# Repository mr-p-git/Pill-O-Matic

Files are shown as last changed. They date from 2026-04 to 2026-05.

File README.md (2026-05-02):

# Pill-O-Matic: Real-Time Scheduled Automatic Pill Dispenser

- Arduino-based automatic pill dispenser with sensor-driven safety logic and stepper-controlled mechanical dispensing.

## Documentation

- [System Design and Implementation](Pill-O-Matic_System_Design_and_Implementation.md) 
- [Project Summary](Pill-O-Matic_Project_Summary.md) 

## Demonstration
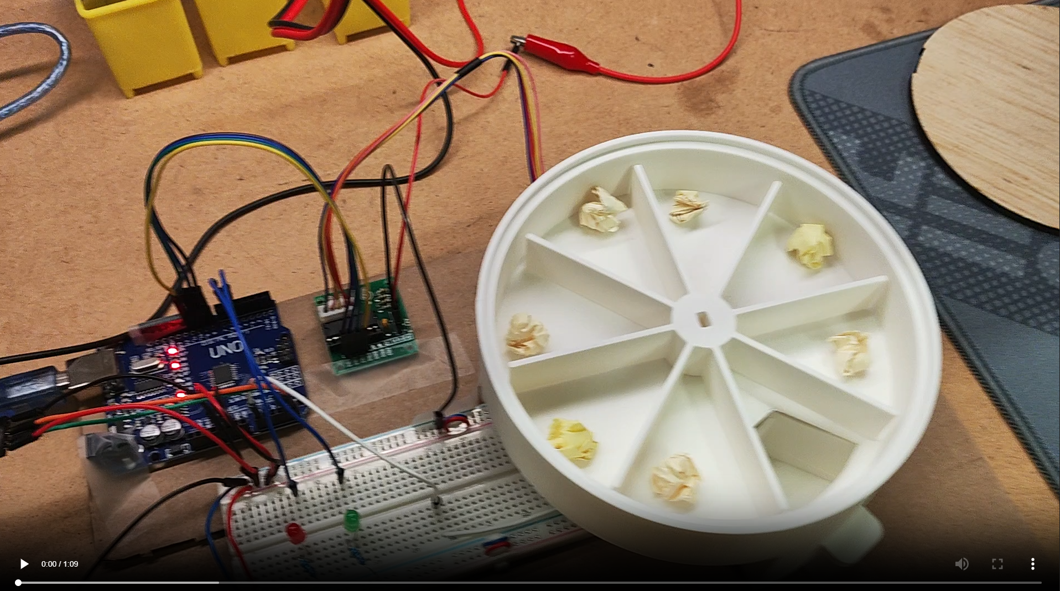
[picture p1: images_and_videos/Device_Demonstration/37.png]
Pill-O-Matic Demo (https://github.com/user-attachments/assets/4b54a555-bc47-4cf3-90d2-f38e5f574e28)


## Project Overview

Pill-O-Matic is a real-time scheduled automatic pill dispenser designed to deliver single doses of medication at predefined times throughout the day. The system integrates sensing, timing, control logic, and mechanical actuation to ensure reliable and user-aware dispensing.

An Arduino Uno coordinates the system using a DS3231 real-time clock (RTC) module for accurate scheduling. At each scheduled time, the system verifies tray presence using an analog Hall effect sensor before actuating a stepper motor to rotate a compartmentalized pill wheel and dispense one dose. The system prevents incorrect operation through state-based logic, ensuring pills are only dispensed when appropriate conditions are met.

## Technical Highlights

- **Embedded firmware development:** Programmed Arduino control logic for RTC-based scheduling, Hall sensor tray detection, LED status feedback, and stepper motor actuation.
- **Electromechanical system integration:** Integrated sensing, timing, motor control, and mechanical dispensing into a coordinated automated medication system.
- **Sensor-based safety control:** Used tray-presence detection to prevent dispensing when the tray is missing and reduce the risk of duplicate or unsafe dispensing.
- **Real-time scheduled operation:** Implemented DS3231 RTC-based dose timing so dispensing events occur autonomously at predefined medication times.
- **Indexed stepper motor control:** Drove a 28BYJ-48 stepper motor through a ULN2003 driver to rotate the pill wheel by fixed increments for single-dose dispensing.
- **State-based control logic:** Structured system behavior around idle, tray-missing, dispensing, and pill-waiting states for predictable user interaction.
- **Power-conscious actuator design:** De-energized the stepper motor when idle to reduce heat, current draw, and unnecessary standby power use.
- **Rapid hardware prototyping:** Fabricated and tested a mixed-material prototype combining 3D-printed PLA mechanisms, embedded magnets, a plywood lid, and cardboard-mounted electronics.

## Key Features

- Real-time scheduled dispensing using RTC-based timing  
- Sensor-based tray detection using analog Hall effect sensor (SS49E)  
- Stepper motor-driven mechanical indexing (45° per dose)  
- State-based control logic to prevent missed or duplicate dispensing  
- User interaction detection via tray removal (no buttons required)  
- Energy-efficient motor control with zero idle current draw  

## System Architecture

- **Controller:** Arduino Uno  
- **Timing Module:** DS3231 Real-Time Clock (RTC)  
- **Sensor:** SS49E Analog Hall Effect Sensor  
- **Actuator:** 28BYJ-48 5V Stepper Motor + ULN2003 Driver  
- **User Feedback:** Red and Green LEDs  
- **Power:** External 5V supply for motor (shared ground with Arduino)  

## System Operation

1. The RTC continuously tracks real time  
2. The Arduino checks scheduled dispensing times  
3. The Hall sensor verifies tray presence  
4. If conditions are met, the stepper motor rotates 45° to dispense one dose  
5. The system waits for tray removal before allowing the next dispense  
6. If the tray is missing or a pill is still present, dispensing is blocked  

## Fabrication and Materials

- 3D-printed PLA pill wheel and tray for precise geometry  
- Plywood lid for enclosure support and accessibility  
- Solderless breadboard for circuit prototyping  
- Embedded magnets for tray detection  

## Key Design Decisions

- Selected Hall effect sensing over force-based detection due to low pill weight, improving reliability  
- Implemented state-based logic to handle missed doses and prevent unsafe operation  
- Disabled stepper motor holding current to reduce power consumption and prevent overheating  
- Designed mechanical clearances to ensure smooth motion without post-processing  
- Used a hybrid material approach (PLA + plywood) to balance precision and structural simplicity  

## Future Improvements

- Improve enclosure robustness and overall durability  
- Integrate user interface (LCD display or alert system)  
- Add battery power for standalone operation  
- Enable wireless connectivity for remote monitoring and notifications  
- Expand system with data logging and health tracking features  

## Outcome

This project demonstrates the successful design and integration of an electromechanical system combining hardware, firmware, and mechanical components. The final prototype reliably performs time-based dispensing with sensor-driven safety logic and efficient power management, showcasing practical engineering problem-solving and system-level thinking.

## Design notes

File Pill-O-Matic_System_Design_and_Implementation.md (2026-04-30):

# Pill-O-Matic: Real-Time Scheduled Automatic Pill Dispenser

## Project Description

This project presents the design and implementation of a real-time clock-based automatic pill dispenser that delivers medication at predefined times throughout the day. The system integrates sensing, timing, control logic, and actuation to ensure reliable and user-aware dispensing. The core of the system is an Arduino Uno, which coordinates all subsystems. A DS3231 real-time clock module provides accurate timekeeping and enables scheduling of multiple daily dose times. At each scheduled time, the system checks the state of the pill tray using an analog Hall effect sensor (SS49E), which detects whether the tray is inserted via mini magnets. If the tray is in place, a 28BYJ-48 5V stepper motor, driven by a ULN2003 driver, rotates a compartmentalized pill wheel by 45 degrees to dispense one dose. A green LED indicates that a pill has been dispensed and is waiting in the tray, while a red LED indicates that the tray is missing and dispensing is temporarily blocked. The system implements state-based control logic to ensure safe and correct operation, including detecting tray removal as a user action to take the medication and preventing dispensing when:

- the tray was not removed following the dispense of a previous dose, indicating that the user forgot to take the pills, and the pills are still in the tray.
- the tray is absent, indicating that the user forgot to return the tray.

The mechanical structure of the dispenser consists of a 3D-printed pill wheel and tray, fabricated using PLA to enable precise geometry and rapid prototyping of the rotating compartment system, while providing rigidity and stability for mounting the motor and holding multiple doses of medication. A plywood lid is used to enclose and support the top of the device, allowing easy access for maintenance and refilling. This combination of materials allows for a balance between cost, manufacturability, structural support, and ease of modification during the design process. Additionally, the motor is fully de-energized after each movement to minimize power consumption and prevent overheating. The circuit is implemented on a solderless breadboard as a functional prototype, demonstrating a complete and integrated electromechanical system without permanent embedded hardware fabrication.The system was validated through repeated testing across multiple scheduled events, demonstrating reliable time-based triggering, consistent mechanical dispensing, and stable sensor-driven state transitions. Future work may focus on improving enclosure robustness, integrating a user interface such as an LCD display or alert system, and enabling wireless connectivity for remote monitoring and configuration, moving the design toward a deployable assistive device.

## Key Features

- Time-based automated pill dispensing using RTC scheduling
- Sensor-driven safety logic to prevent incorrect dispensing
- Mechanical indexing system with precise 45° rotation per dose
- Energy-efficient motor control with zero idle current draw
- User-aware interaction via tray detection instead of manual input

## Design Constraints

1. Budget control: $200 max
2. Include electrical, mechanical, and software/firmware system

## Engineering Challenges and Design Decisions

- Selected Hall effect sensing over force-based detection after determining that pill mass was insufficient for reliable actuation, improving system robustness.
- Implemented state-based control logic to handle edge cases such as missed doses and tray removal, ensuring safe and predictable operation.
- Optimized stepper motor control by eliminating idle coil energization, reducing power consumption and preventing thermal buildup.
- Designed precise mechanical interfaces using calibrated clearances (0.2–0.6 mm) to ensure proper fits and reliable motion without post-processing.
- Balanced material selection by combining 3D-printed PLA for complex geometry and plywood for structural simplicity and accessibility.

## System Architecture

### Microcontroller

- Arduino UNO R3: program the RTC so that at a preset time, pill would be dispensed. Program the Stepper motor to rotate 1/8 of a full rotation everytime it receives a signal from the RTC.

### Input Devices

- DS3231 RTC module: a real-time-clock module. Pre-set time to take pill (e.g 8:00 a.m. EST). Sends signal to stepper motor to rotate 1/8 of a full rotation, turns on Green LED when it's time to take pill.

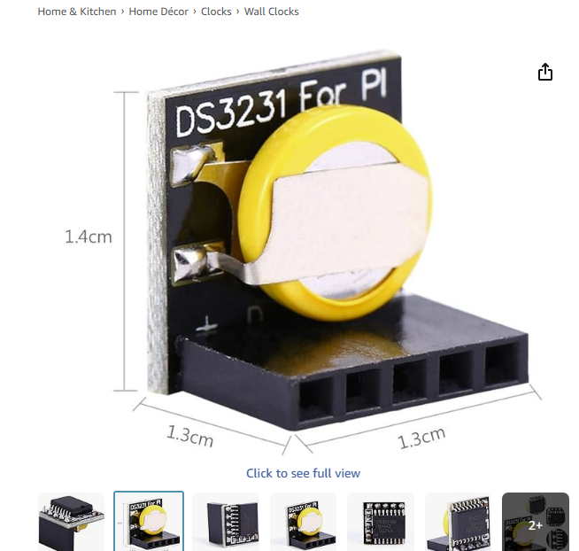
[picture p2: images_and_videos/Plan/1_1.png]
  

- Hall Effect Sensor SS49E: senses wheter the pill tray is inserted or removed. If removed, lights up Red LED to remind user to return pill tray, and also prevent dispensing of next pill while tray is removed.

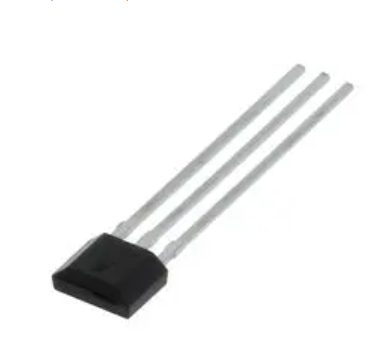
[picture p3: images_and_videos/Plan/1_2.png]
  

### Output Devices

- ULN2003 Driver Board & Stepper Motor 28BYJ-48: rotates 1/8 turn to dispense next dose of pill, when signal recieved from RTC module.
- Green LED: turns on when signal recieved from RTC module, reminding user it is time to take pill. Turns off when pill tray removal detected through input of hall effect sensor.
- RED LED :turns on when tray is removed, turns off when tray is returned. Using hall effect sensor, and embedded magnet in the tray.

### Actuator

- ULN2003 Driver Board & Stepper Motor 28BYJ-48: rotates 1/8 turn to dispense next dose of pill, when signal recieved from RTC module.

### Sensor

- Magnet & Hall Effect Sensor SS49E: senses wheter the pill tray is inserted or removed.

## Materials used

1. Prusament PLA for:
   - Chamber leaves
   - Container Base (body of Automatic Pill Dispenser)
   - Pill tray

2. Plywood for:
   - Lid

## Bill of Materials

| Item No. | Item Name | Description | Quantity | Source | Cost ($) |
| --- | --- | --- | --- | --- | --- |
| 1 | Arduino Uno R3 | Main microcontroller board controlling entire system | 1 | [Amazon](https://www.amazon.ca/Elegoo-Board-ATmega328P-ATMEGA16U2-Arduino/dp/B01EWOE0UU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) | 21.99 |
| 2 | DS3231 RTC Module | Real-time clock module for scheduling pill dispensing | 1 | [Amazon](https://www.amazon.ca/DS3231-Precision-Memory-Arduino-Raspberry/dp/B07F1349S3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) | 4.63 |
| 3 | ULN2003 Driver + 28BYJ-48 Stepper Motor set | 5V stepper motor for rotating pill wheel | 1 | [Amazon](https://www.amazon.ca/Stepper-ULN2003-Driver-28BYJ-48-4-Phase/dp/B0B1F3DJYF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) | 5.82 |
| 4 | Hall Effect Sensor (SS49E) | Magnetic sensor for detecting tray insertion and removal | 1 | [Newark](https://canada.newark.com/honeywell/ss49e/hall-effect-sensor-linear-sip/dp/09J1786) | 0.89 |
| 5 | Mini Disc Magnets (5×3 mm) | Magnets used to trigger Hall effect sensor | 4 | [Amazon](https://www.amazon.ca/dp/B09MMX6NN3?ref=ppx_yo2ov_dt_b_fed_asin_title&th=1) | 0.8 |
| 6 | Green LED | Indicates pill dispensed / waiting state | 1 | [Newark](https://www.newark.com/multicomp-pro/mcl034lgd/led-green-t-1-3mm-3-2mcd-570nm/dp/14N9376?MER=sy-me-pd-mi-alte) | 1.05 |
| 7 | Red LED | Indicates tray missing / system status | 1 | [Newark](https://www.newark.com/broadcom/hlmp-d150/led-5mm-red-3mcd-637nm/dp/39K9949) | 0.60 |
| 8 | 220Ω Resistors | Current-limiting resistors for LEDs | 2 | [Amazon](https://www.amazon.ca/uxcell-Tolerance-Resistors-Electronic-Experiments/dp/B07LGLC192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) | 0.1 |
| 9 | Breadboard | Prototyping board for circuit connections | 1 | [Amazon](https://www.amazon.ca/Breadboard-Solderless-Prototype-Distribution-Connecting/dp/B01EV6LJ7G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) | 4.33 |
| 10 | Jumper Wires | Used for electrical connections | 1 unit | [DigiKey](https://www.digikey.ca/en/products/detail/encore-wire/C2003A-12-02/4455018) | 1.65 |
| 11 | Prusament PLA | Used for 3D printed parts | 267.51 g | Local hardware store | 7.49 |
| 12 | Plywood | Used for top lid | 1 | Local hardware store | 1.5 |
| 13 | Screws | Used to secure the stepper motor to the container base | 2 | Local hardware store | 0.2 |
| | | | | | **Total Cost: $51.05** |

## Concept Development

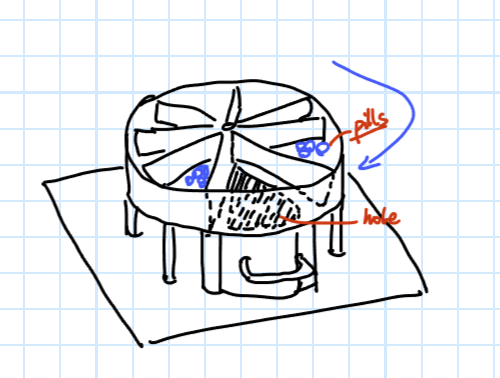
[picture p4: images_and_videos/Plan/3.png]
Rough Draft


## System Operation

### Initial Design Flow Chart

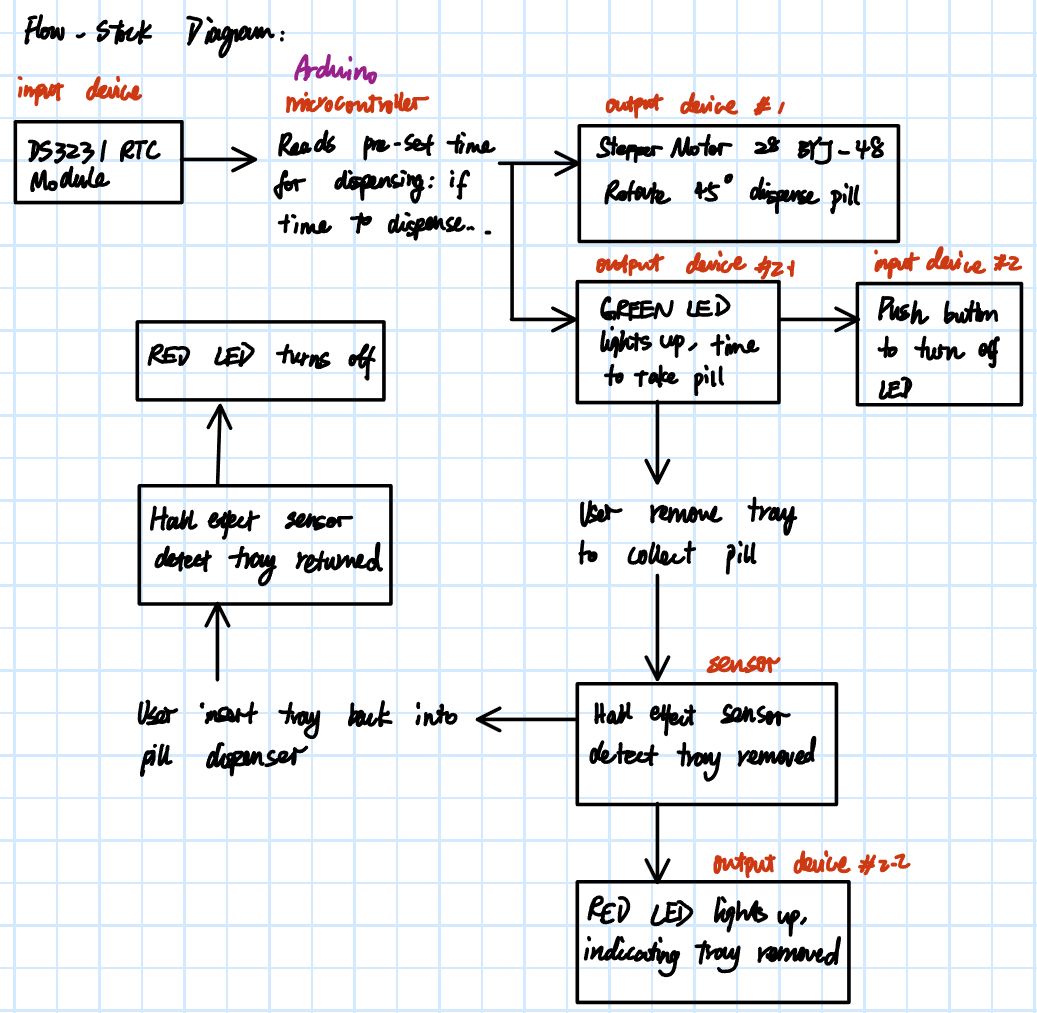
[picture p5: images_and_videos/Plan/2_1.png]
Initial Design Flow Chart


### Finalized Design Flow Chart

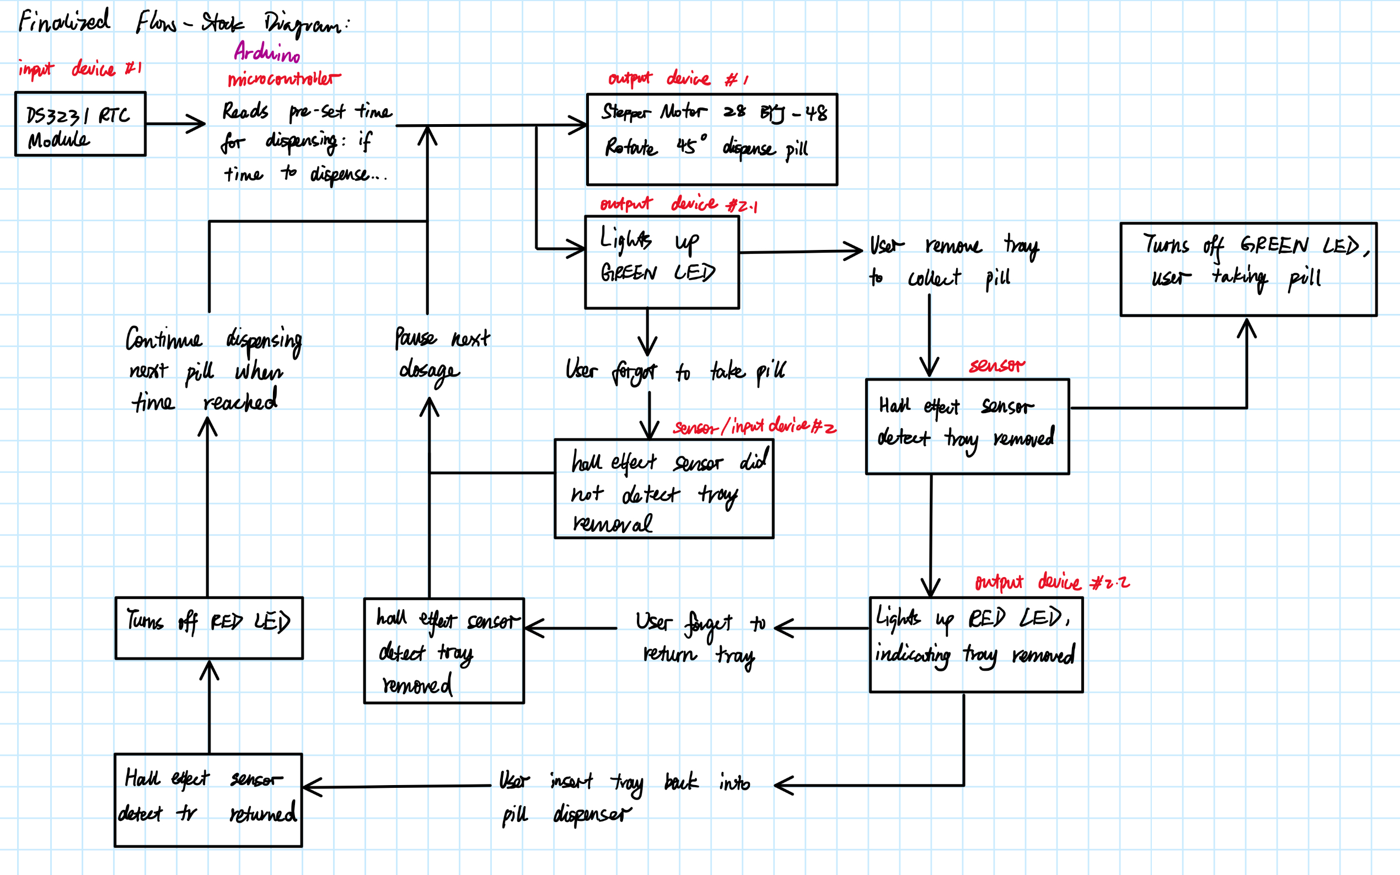
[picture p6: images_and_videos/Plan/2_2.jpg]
Finalized Design Flow Chart


## CAD of Automatic Pill Dispenser

### Components

Click [here](files/1_CAD_pill-dispenser/) to view the CAD files and Exploded View Drawings.

- Chamber Leaves
- Container Base
- Pill Tray

### Total Clearance used in design

| Fit Type | Total Clearance |
| --- | --- |
| Loose sliding fit | 0.6 mm |
| Sliding fit | 0.4 mm |
| Tight fit | 0.2 mm |

### Chamber Leaves

#### Top view

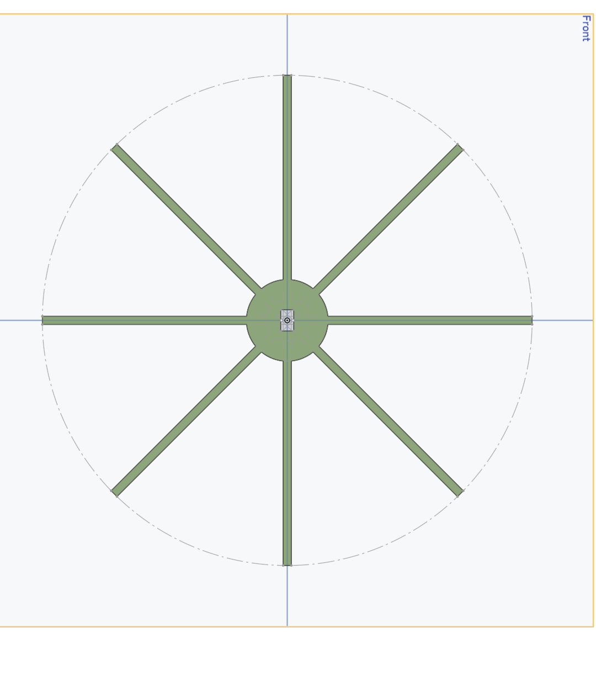
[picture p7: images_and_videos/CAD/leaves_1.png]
Chamber Leaves


#### Side view 1

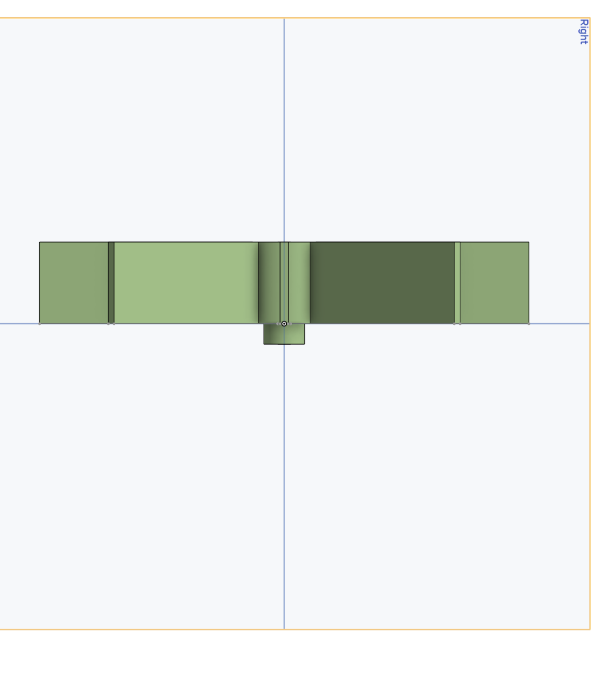
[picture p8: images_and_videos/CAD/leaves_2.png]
Chamber Leaves


#### Side view 2

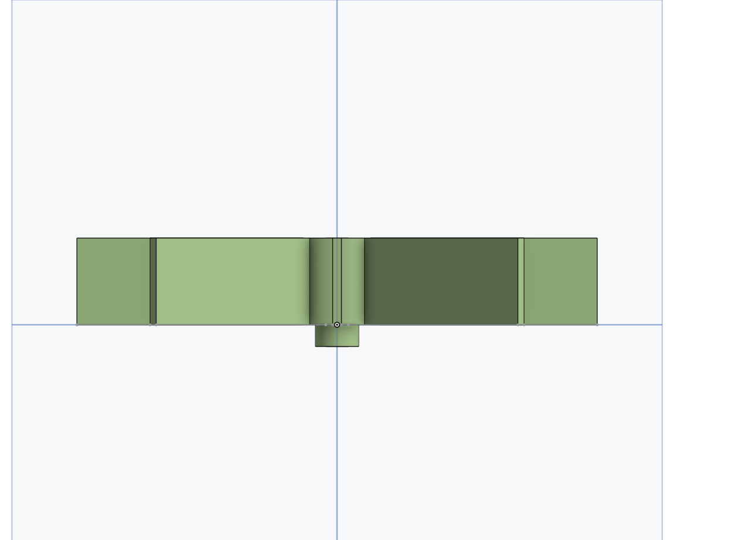
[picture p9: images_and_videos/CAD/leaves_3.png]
Chamber Leaves


#### Isometric

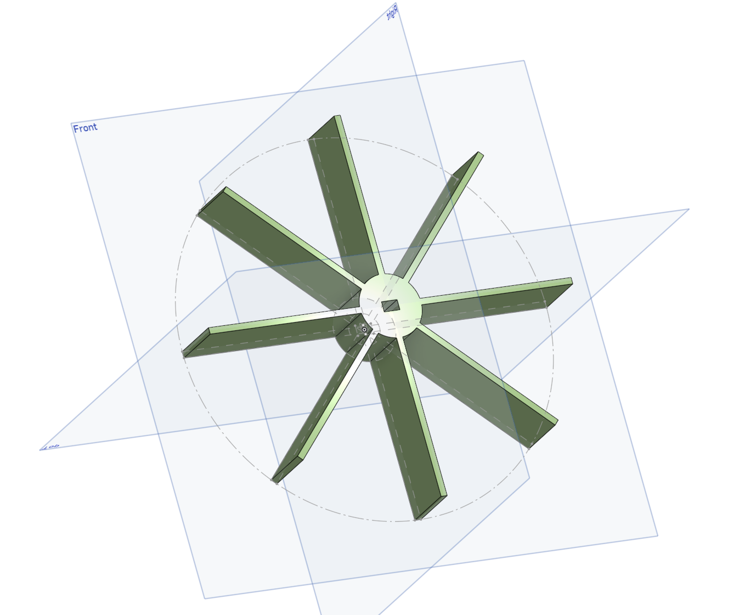
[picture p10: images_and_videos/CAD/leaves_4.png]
Chamber Leaves


### Container Base

#### Top view

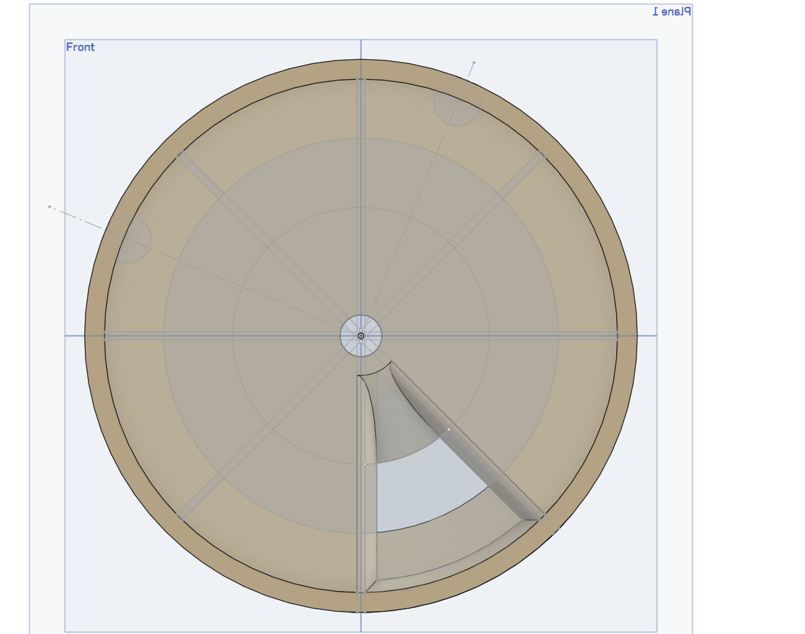
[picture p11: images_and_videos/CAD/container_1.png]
Container Base


#### Side view

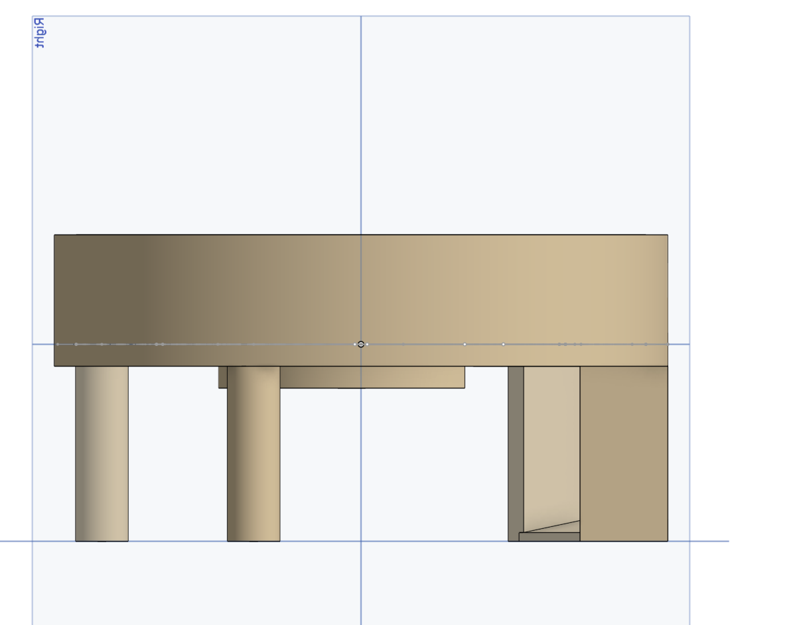
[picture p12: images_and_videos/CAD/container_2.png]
Container Base


#### Side view

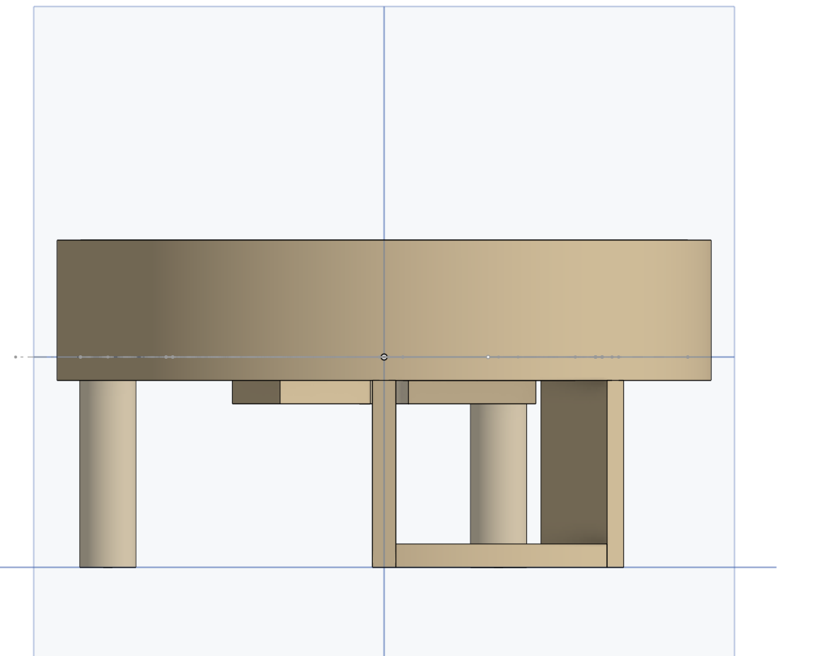
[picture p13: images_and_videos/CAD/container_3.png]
Container Base


#### Isometric 1

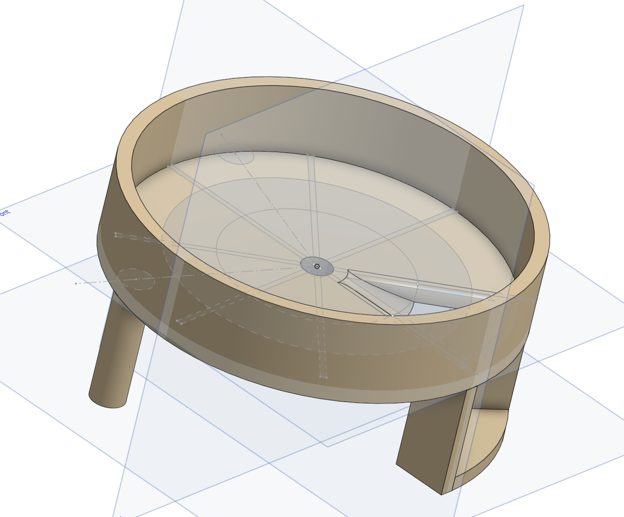
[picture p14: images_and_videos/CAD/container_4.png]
Container Base


#### Isometric 2

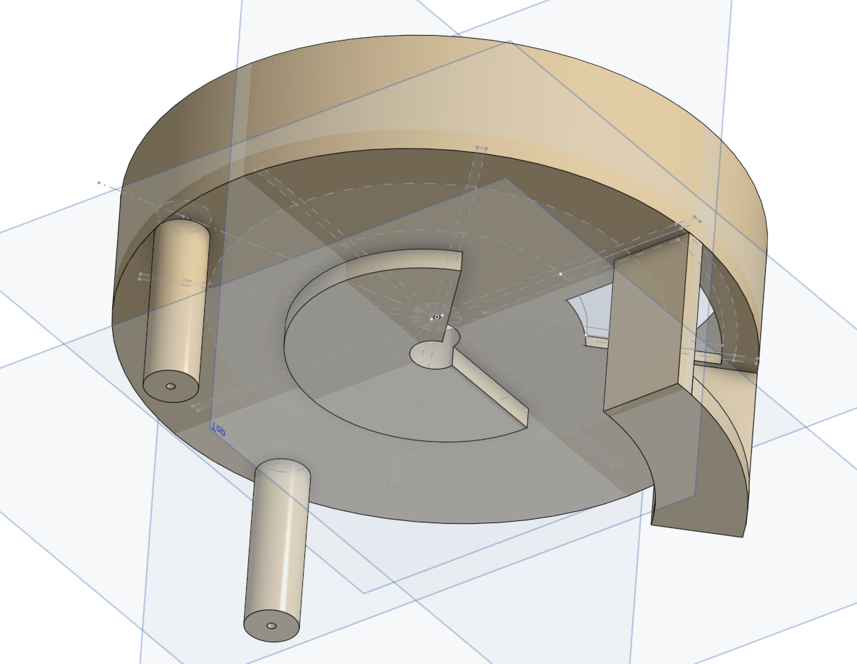
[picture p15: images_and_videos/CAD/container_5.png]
Container Base


### Pill Tray

#### Top view

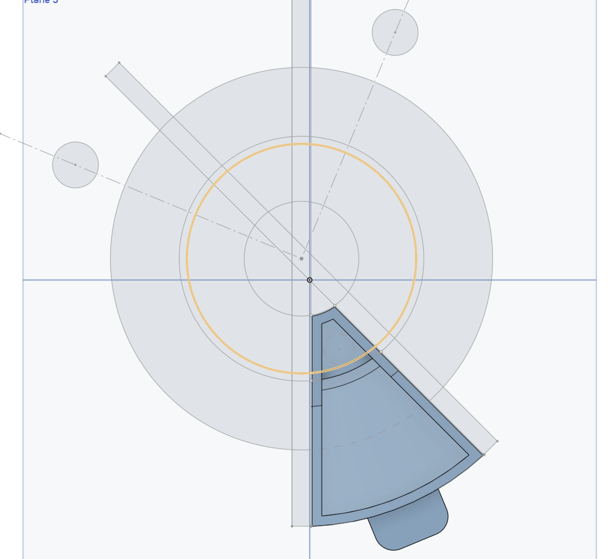
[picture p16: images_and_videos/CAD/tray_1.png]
Pill Tray


#### Side view

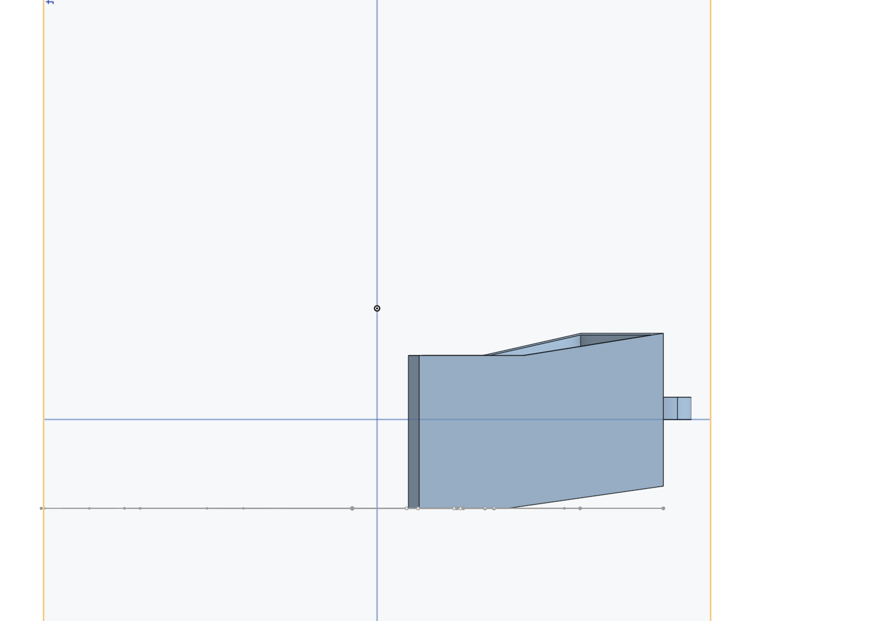
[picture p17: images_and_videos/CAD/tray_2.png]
Pill Tray


#### Front view

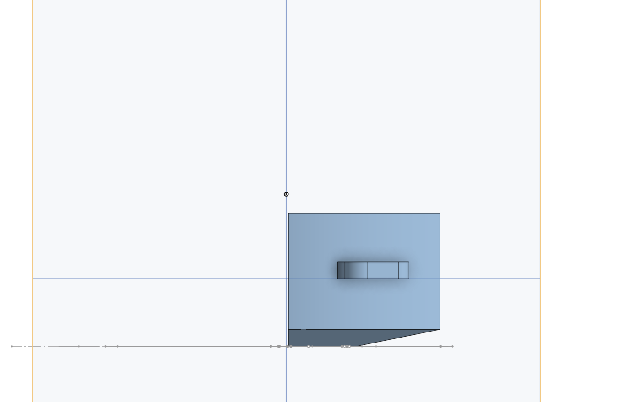
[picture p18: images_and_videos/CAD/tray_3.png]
Pill Tray


#### Isometric

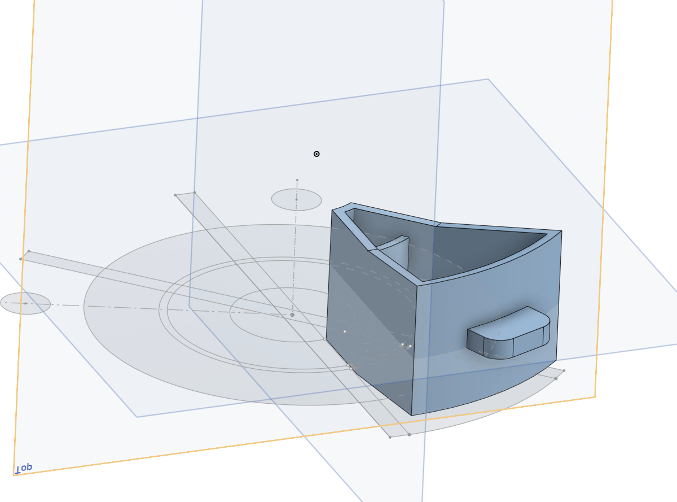
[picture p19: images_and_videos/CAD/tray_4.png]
Pill Tray


### Assembly

#### Top view

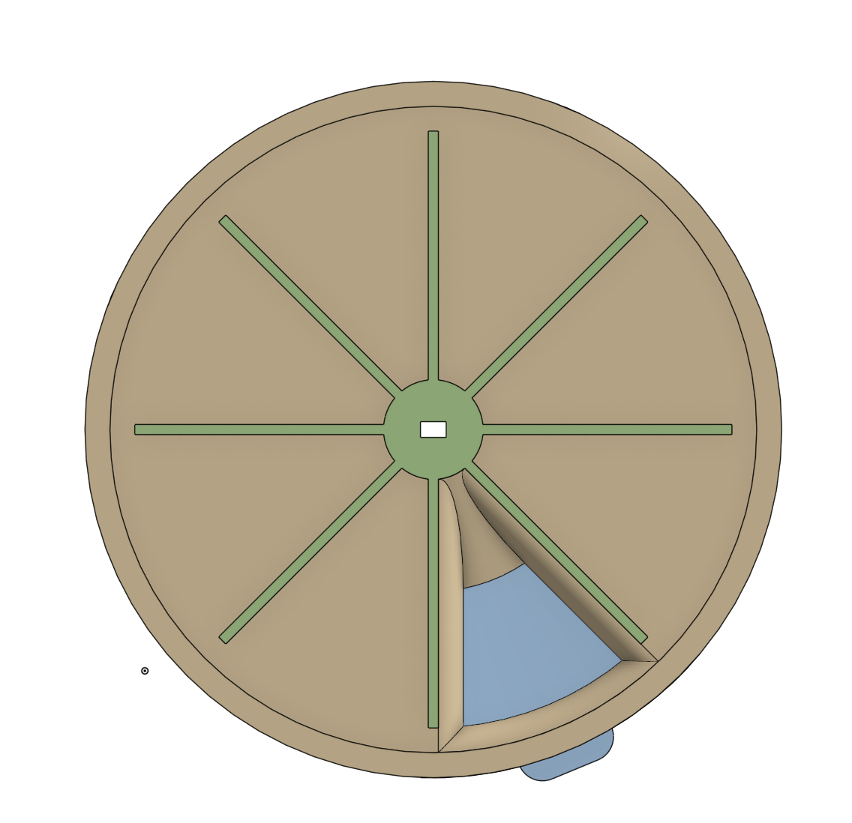
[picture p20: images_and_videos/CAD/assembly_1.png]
Assembly


#### Isometric 1

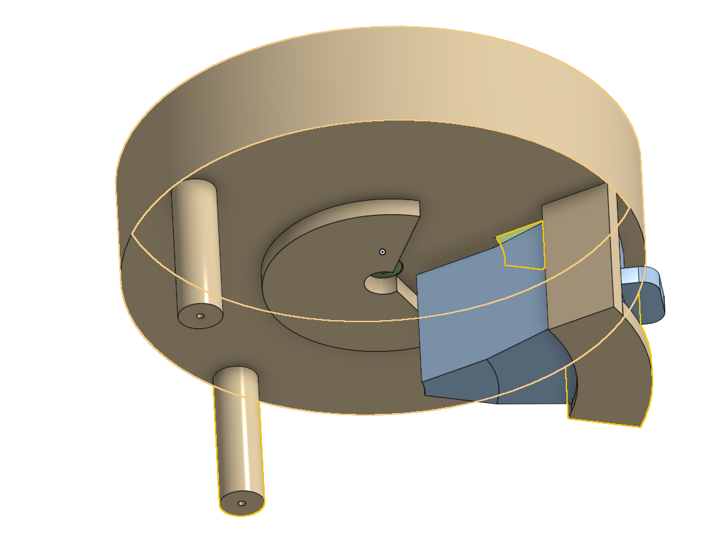
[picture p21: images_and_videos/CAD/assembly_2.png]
Assembly


#### Isometric 2

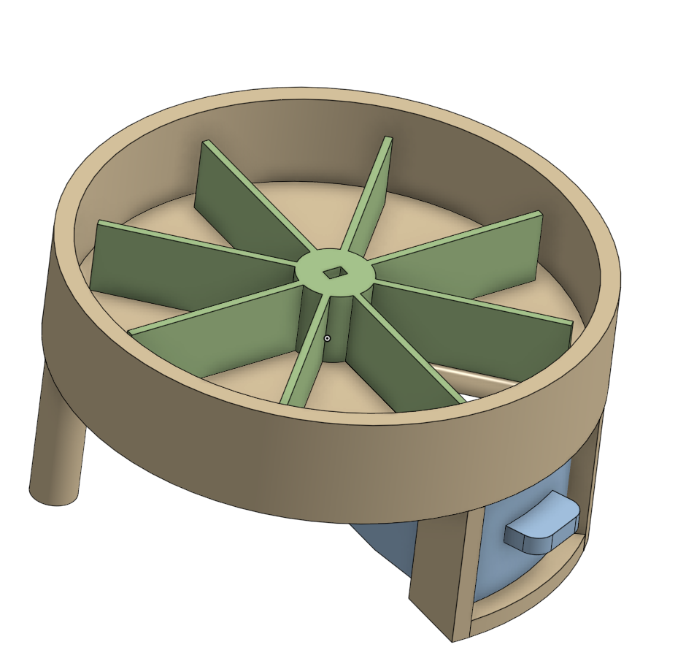
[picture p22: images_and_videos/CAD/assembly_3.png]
Assembly


#### Exploded View

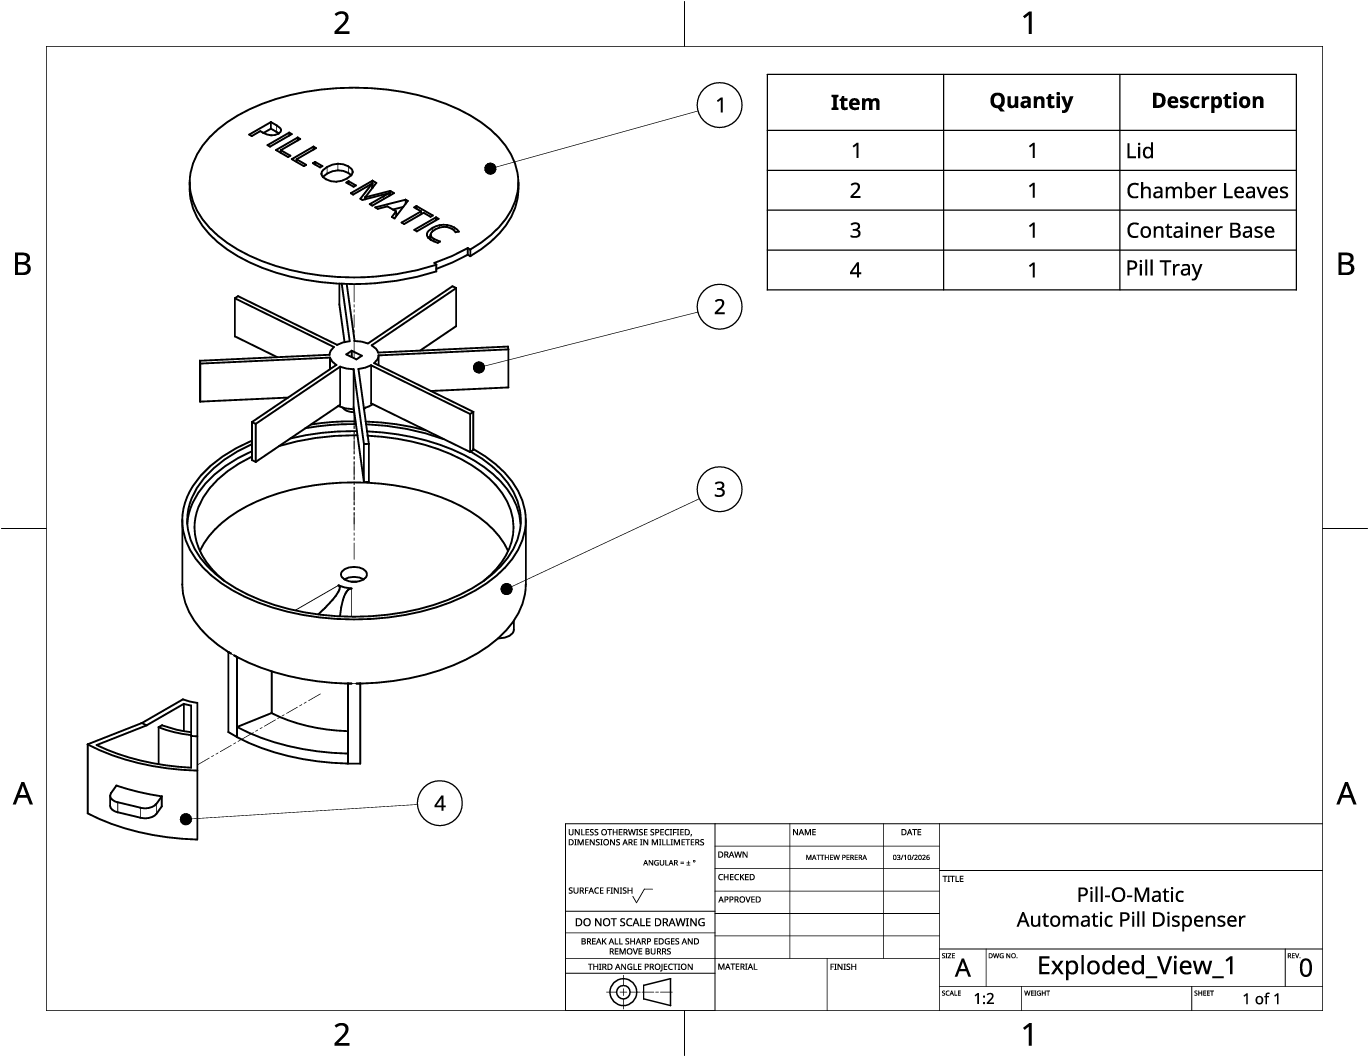
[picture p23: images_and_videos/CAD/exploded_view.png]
Exploded View


## 3D Printing of Parts

#### Overview of the 3D Printed Parts
Pill-O-Matic: Real-Time Scheduled Automatic Pill Dispenser
Click [here](files/3_3d_print_pill-dispenser/) to view the 3D printing files.

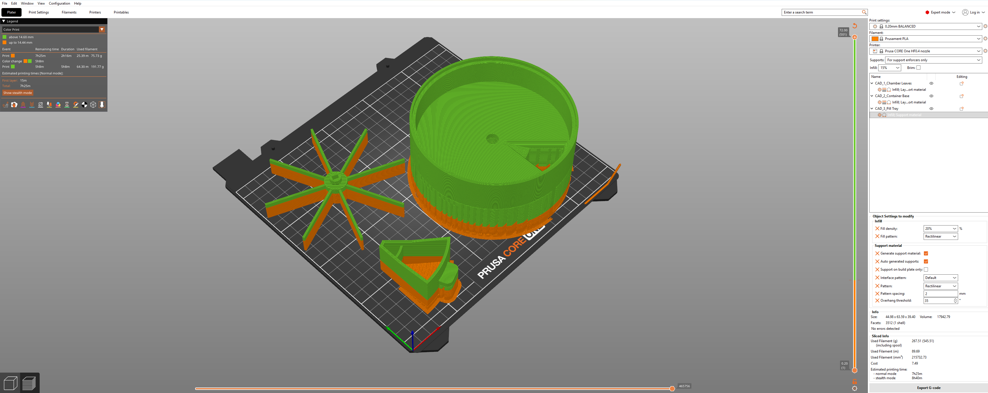
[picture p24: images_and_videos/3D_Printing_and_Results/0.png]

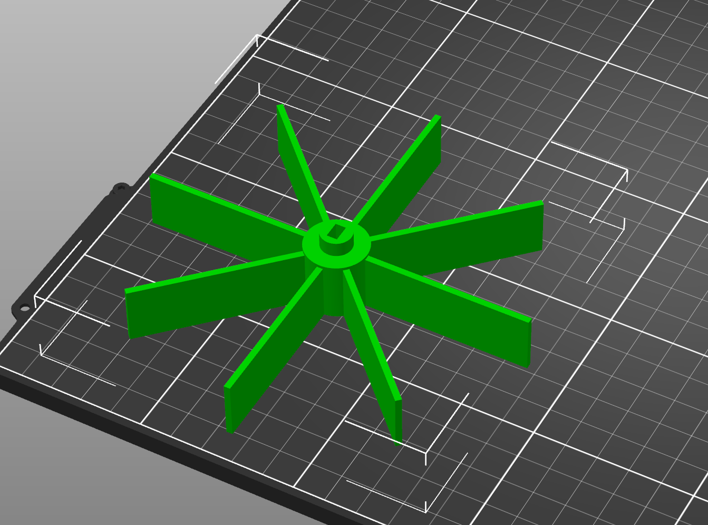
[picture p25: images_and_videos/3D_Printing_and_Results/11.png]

Overview of the 3D Printed Parts
Overview of the 3D Printed Parts

#### Print Results

Results
Results
Results
Results
Results

## Subsystem Validation

### Hall Effect Sensor Module

#### Overview

Hall Effect Sensor Module
Hall Effect Sensor Module

#### Breadboard wiring

Hall Effect Sensor Module

#### Arduino UNO wiring

Hall Effect Sensor Module

#### CLICK IMAGE BELOW TO VIEW VIDEO

Hall Effect Sensor Module

### RTC Module

#### Overview

RTC Module

#### Arduino UNO wiring

RTC Module

#### CLICK IMAGE BELOW TO VIEW VIDEO

RTC Module

## Final System Circuit Diagram

Click [here](images_and_videos/Plan/Pill-O-Matic_circuit.png) to view the circuit diagram: Pill-O-Matic_circuit.png

Final System Circuit Diagram

## Final System Demonstration

Click [here](files/4_code/Pill_O_Matic_code/Pill_O_Matic_code.ino) to view the source code.

### Overview

Overview

#### CLICK IMAGES BELOW TO VIEW VIDEO

Demonstration: pill dispensing at pre-set time

Demonstration: pill dispensing at pre-set time

### Breadboard wiring

Breadboard wiring

### Arduino UNO wiring

Arduino UNO wiring

### Hall Effect Sensor SS49E Placement

Hall Effect Sensor SS49E Placement

### ULN2003 Driver Board & Stepper Motor 28BYJ-48 wiring

ULN2003 Driver Board & Stepper Motor 28BYJ-48 wiring

#### Special note on Stepper Motor 28BYJ-48

- The system uses Stepper Motor 28BYJ-48 5V driven by a ULN2003 driver board, and by default the motor coils remain energized after movement, which causes the motor to keep drawing high current (250 mA) even while idle.

- This default behavior leads to unnecessary power consumption and heat generation, which is undesirable for a pill dispenser that only needs brief indexed motion and does not require continuous holding torque between dispensing events.

- To solve this, a custom `turnOffStepper()` function was added to the code to set all four motor control pins LOW after each movement, which de-energizes the coils and reduces idle current to approximately zero.

```cpp
void turnOffStepper() {
  digitalWrite(motorPin1, LOW);
  digitalWrite(motorPin2, LOW);
  digitalWrite(motorPin3, LOW);
  digitalWrite(motorPin4, LOW);
}

void dispenseOnePill() {
  stepperMotor.step(stepsPerDose);  // Rotate one compartment
  turnOffStepper();                 // De-energize motor after movement
}
```

#### DC Power supply reading: Stepper Motor 28BYJ-48 - OFF

Stepper Motor 28BYJ-48: OFF

#### DC Power supply reading: Stepper Motor 28BYJ-48 - ON

Stepper Motor 28BYJ-48: ON

#### Special Case 1 - to avoid pill piling up in tray: pill dispensed -> user did not take pill -> next dispensign time reached -> pause dispensing of next dosage until pill taken to avoid pill piling up in tray.

Special Case 1 - to avoid pill piling up in tray

#### Special Case 2 - to avoid dispensing pill when tray removed: time to take pill -> pill tray not detected -> wait until pill tray inserted to dispense pill.

Special Case 2 - to avoid dispensing pill when tray removed

## Reflection on the Process

### What: what was done? what went well/not well during the process? what was the result?

#### What was done

- An Arduino-based automatic pill dispenser was designed and built integrating CAD, 3D printing, electronics, and embedded programming.
- The system combined RTC scheduling, sensor feedback, and stepper motor actuation into a single functional design.

#### What went well

- CAD dimensions were accurate, resulting in precise fits and smooth sliding between components.
- Proper clearance selection eliminated the need for rework during assembly.
- A 30% infill base provided strong structural support and reliable screw retention for the motor mount.
- Stepper motor control logic minimized power consumption by de-energizing coils when idle and prevented overheating.
- Edge cases were handled effectively, preventing dispensing when the tray was missing and avoiding over-dispensing when pills were uncollected.
- System integration produced stable and predictable behavior during operation.

#### What did not go well

- The Hall effect sensor had a limited range of approximately 10 mm, requiring close breadboard placement and reducing compactness and aesthetics.
- Excess support material was used during 3D printing, leading to unnecessary material usage and inefficiency.

#### What was the result

- The final outcome was a fully functional and reliable prototype that met all core design objectives.

### So What: what is the importance and significance of what was done?

- The system addresses real-world medication challenges such as missed doses, incorrect pill selection, and reliance on separate reminder systems.
- It automates routine healthcare tasks and reduces cognitive load, especially for elderly or busy users.
- It improves medication adherence by ensuring consistent timing and controlled dispensing.
- It reduces human error by eliminating confusion associated with multi-compartment pill boxes.
- It integrates reminder and dispensing functions into a single system, removing the need for multiple tools.
- It enhances safety by preventing over-dispensing and handling edge cases such as a missing tray or uncollected pills.
- It demonstrates a practical application of embedded systems in solving real healthcare problems.
- It highlights the value of system-level design through the integration of mechanical, electrical, and software components.
- It establishes a foundation for scalable assistive technology that can be extended to smart health monitoring and IoT systems.

### Now What: what could further be done?

- Sensing system can be improved using more compact and reliable alternatives such as limit switches or optical sensors.
- Mechanical design can be optimized to reduce support material in 3D printing and improve print efficiency.
- Electrical system can transition to a perfboard-based embedded design to reduce loose wiring and improve reliability and portability.
- Power system can be upgraded with battery integration to improve potability and enable standalone operation.
- The Hall Effect Sensor can be mounted independently from the breadboard to allow flexible placement and a cleaner design.
- Additional system features can be added, including voice or audio reminders, missed-dose tracking, and safety lock mechanisms.
- An LCD/touch screen display can be integrated to enable user input without having to touch code, effectively improving usability and user feedback.
- IoT connectivity can be integrated to enable real-time monitoring, mobile app notifications, and caregiver alerts for missed doses.
- The system can be expanded into a smart health platform with data logging, usage analytics, and integration with wearable or health systems for long-term tracking.

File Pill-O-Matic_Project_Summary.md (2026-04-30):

# Pill-O-Matic: Real-Time Scheduled Automatic Pill Dispenser

## Project Description

Designed and built a real-time clock-based automatic pill dispenser that delivers single doses at predefined times throughout the day. The system integrates sensing, control logic, and mechanical actuation to ensure reliable and user-aware dispensing.

An Arduino Uno coordinates the system using a DS3231 real-time clock (RTC) module for accurate scheduling. At each scheduled time, the system verifies tray presence using an analog Hall effect sensor before actuating a 28BYJ-48 stepper motor (via ULN2003 driver) to rotate a compartmentalized pill wheel and dispense one dose. Visual feedback is provided through LEDs to indicate system status and user interaction.

The system implements a state-based control logic to prevent incorrect operation, including blocking dispensing when the tray is absent and detecting tray removal as confirmation that the user has taken the medication. Additionally, the motor is actively de-energized after each movement to eliminate idle current draw and reduce thermal load.

## Key Contributions and Skills Demonstrated

- **Embedded Systems & Control Logic**
  - Developed real-time scheduling using RTC integration and Arduino firmware
  - Implemented state-machine logic for safe dispensing and user interaction tracking

- **Hardware Integration**
  - Integrated sensors, actuators, and driver circuits into a cohesive system
  - Designed and debugged full circuit on a solderless breadboard

- **Electromechanical System Design**
  - Designed and fabricated a rotating pill wheel and tray using 3D-printed PLA
  - Integrated motor-driven actuation with mechanical indexing (45° per dose)

- **Power Optimization**
  - Identified and resolved stepper motor idle current issue by implementing coil de-energization in software

- **System Reliability & Safety**
  - Implemented logic to prevent double dispensing and detect missed doses
  - Designed user-aware interactions using sensor feedback instead of manual inputs

## Fabrication and Materials

- 3D-printed PLA components for pill wheel and tray
- Plywood lid for structural support and accessibility
- Breadboard-based circuit for rapid prototyping and testing

## Outcome

Successfully developed a fully functional prototype demonstrating reliable time-based dispensing, accurate mechanical actuation, and robust sensor-driven control. The project highlights the ability to design and integrate hardware, firmware, and mechanical systems into a complete working device.

## Future Improvements

- Refine enclosure design for durability and manufacturability
- Add user interface (LCD display or alert system)
- Integrate battery power and wireless connectivity for standalone operation

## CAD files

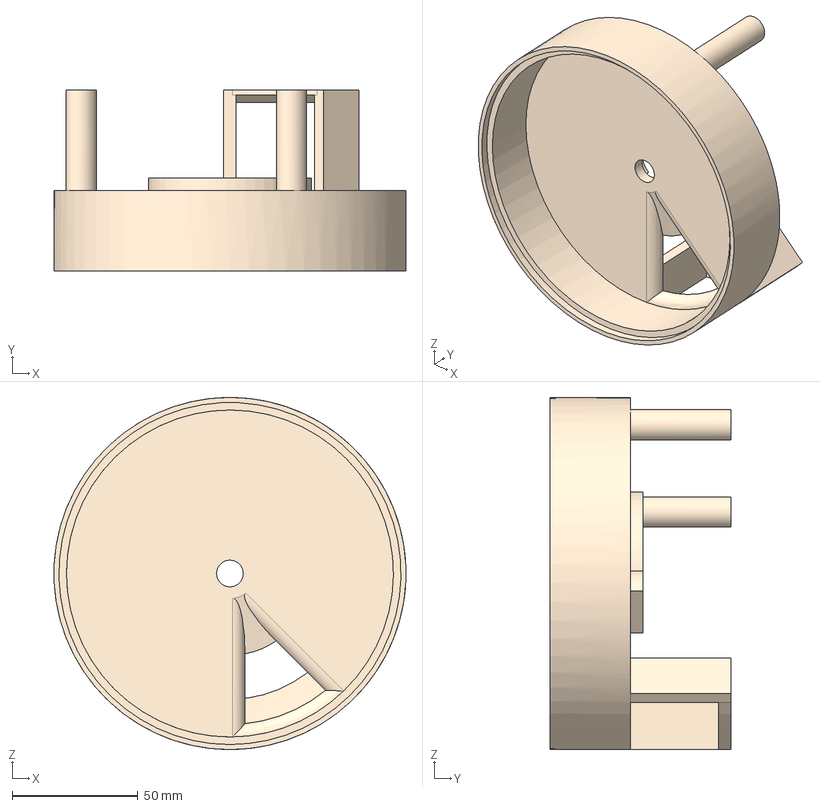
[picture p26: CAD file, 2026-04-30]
files/1_CAD_pill-dispenser/CAD_2_Container Base.step
139.9 x 72.0 x 140.0 mm

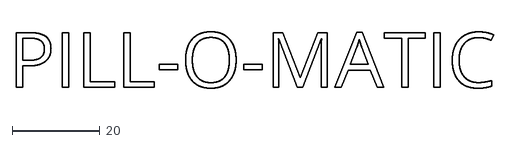
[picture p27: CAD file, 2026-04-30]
files/2_laser_cut_plywood/CAD_2d_lid_sketch_2.dxf
108.9 x 12.9

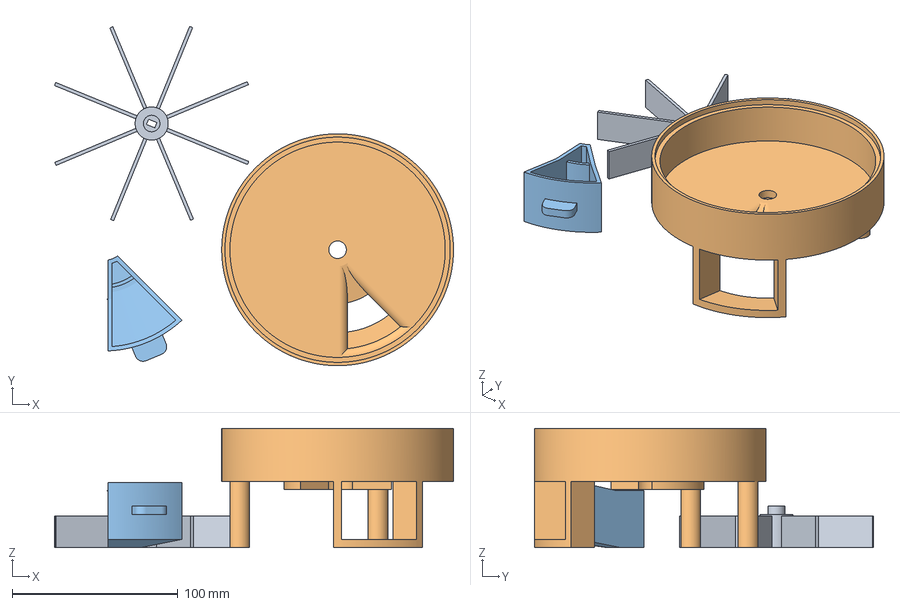
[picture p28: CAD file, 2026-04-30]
files/3_3d_print_pill-dispenser/3D Printing_Pill Dispenser.3mf
241.0 x 204.9 x 72.0 mm
CAD_1_Chamber Leaves
CAD_2_Container Base
CAD_3_Pill Tray

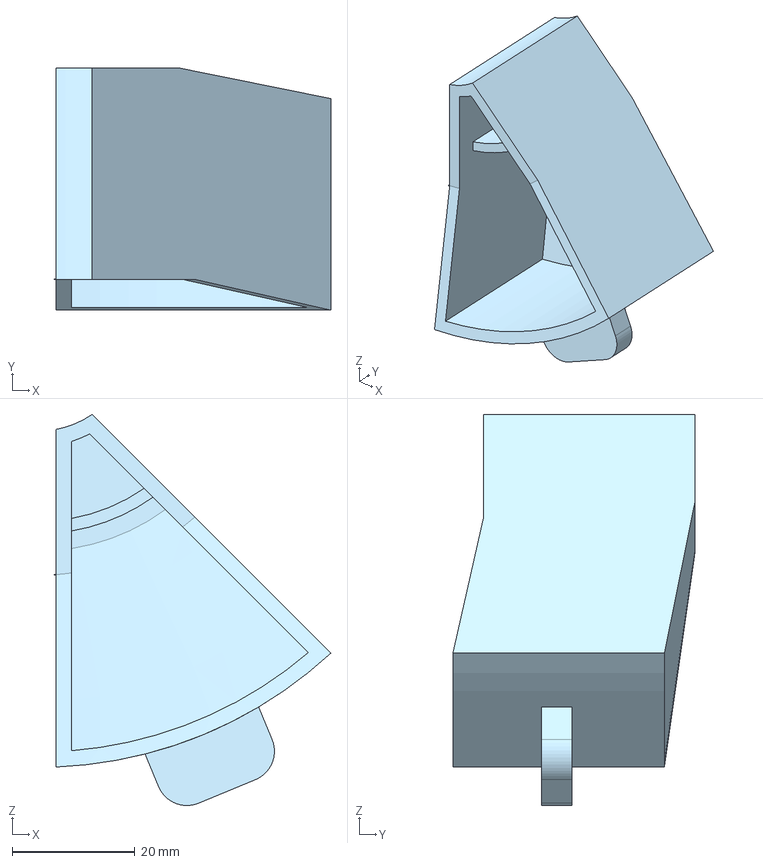
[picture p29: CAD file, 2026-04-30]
files/1_CAD_pill-dispenser/CAD_3_Pill Tray.step
45.0 x 39.4 x 63.6 mm

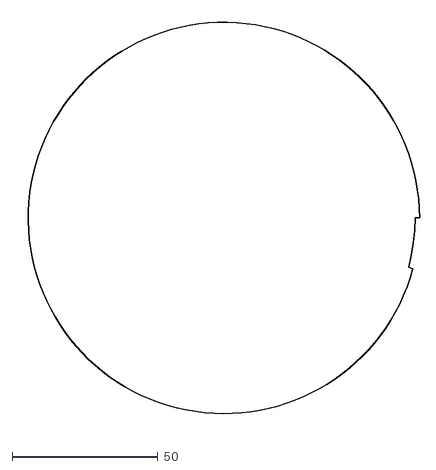
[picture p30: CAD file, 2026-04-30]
files/2_laser_cut_plywood/CAD_2D_lid_sketch_1.dxf
138.0 x 141.8

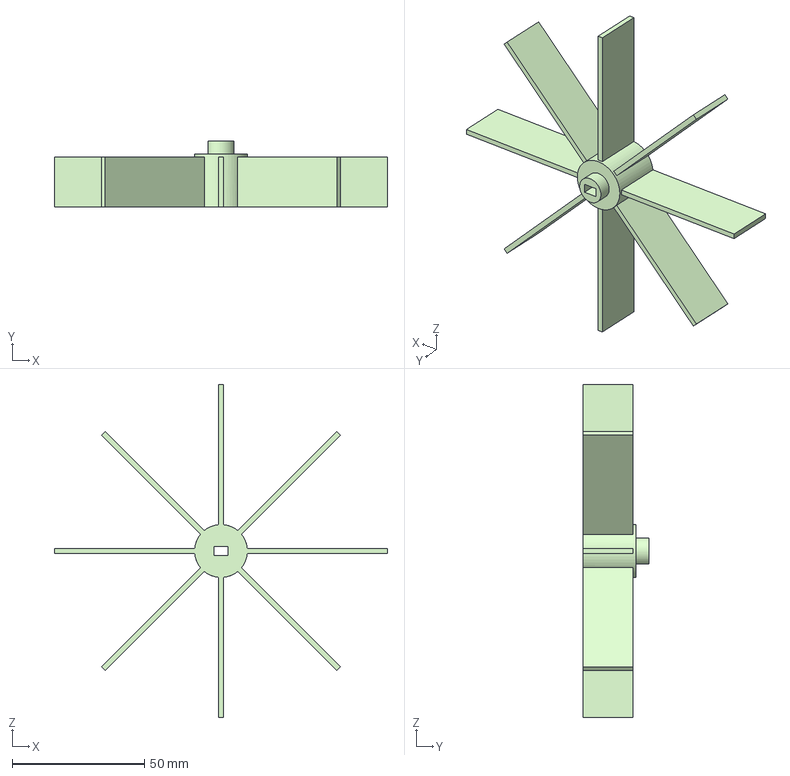
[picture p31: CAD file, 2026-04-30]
files/1_CAD_pill-dispenser/CAD_1_Chamber Leaves.step
126.0 x 25.0 x 126.0 mm

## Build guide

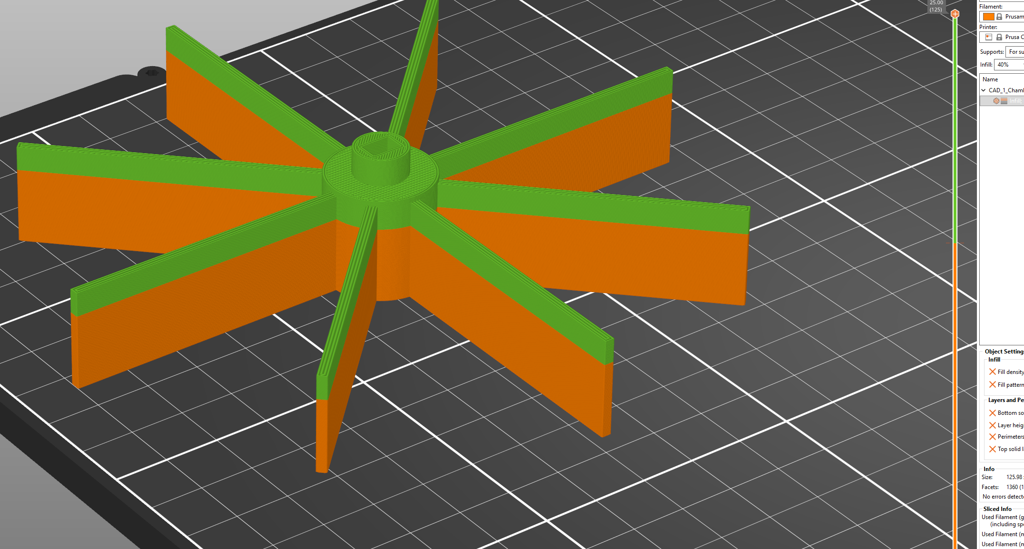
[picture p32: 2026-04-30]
images_and_videos/3D_Printing_and_Results/13.png

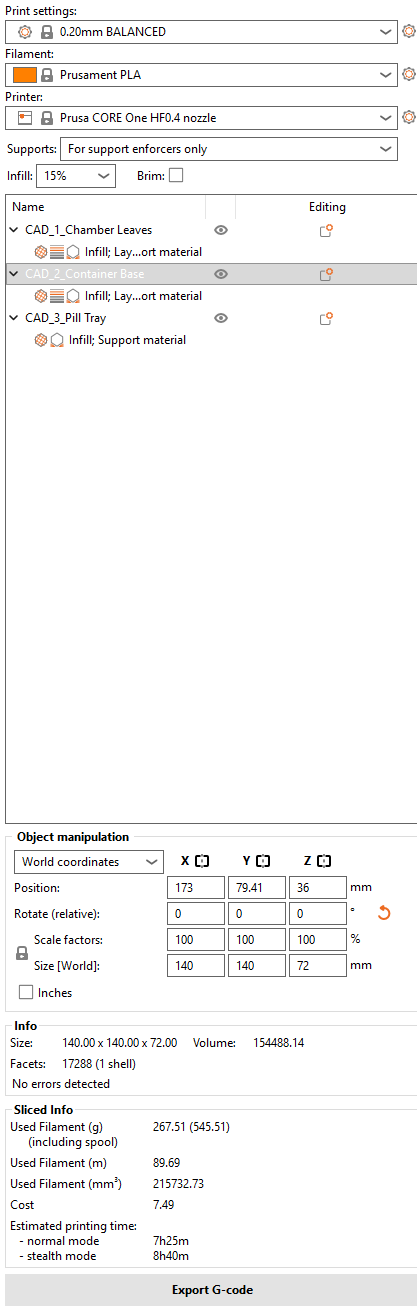
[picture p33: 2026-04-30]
images_and_videos/3D_Printing_and_Results/23.png

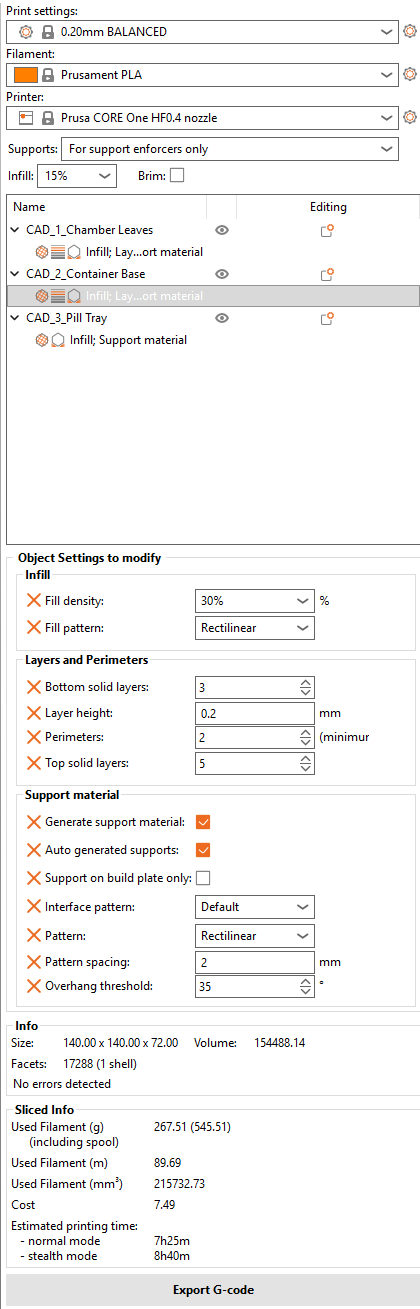
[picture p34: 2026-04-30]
images_and_videos/3D_Printing_and_Results/24.png

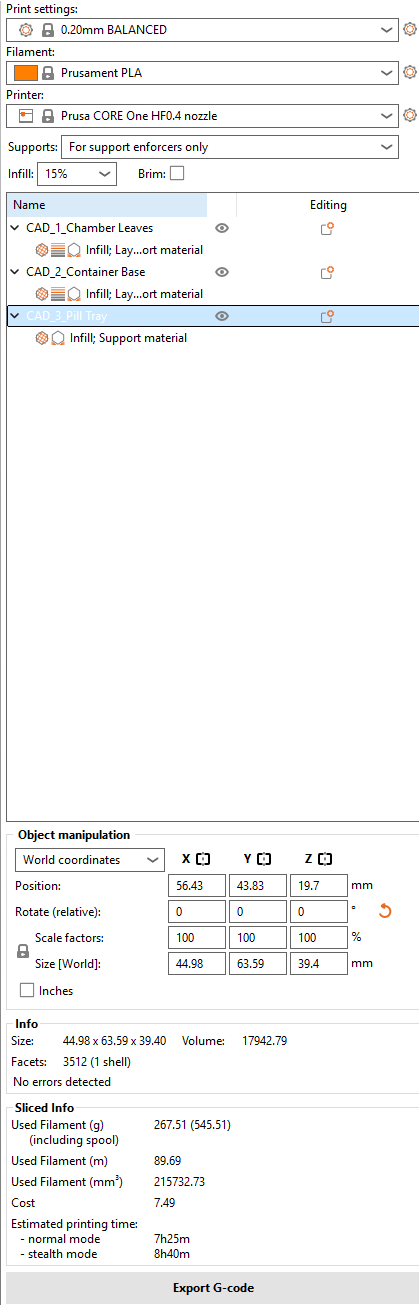
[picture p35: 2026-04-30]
images_and_videos/3D_Printing_and_Results/33.png

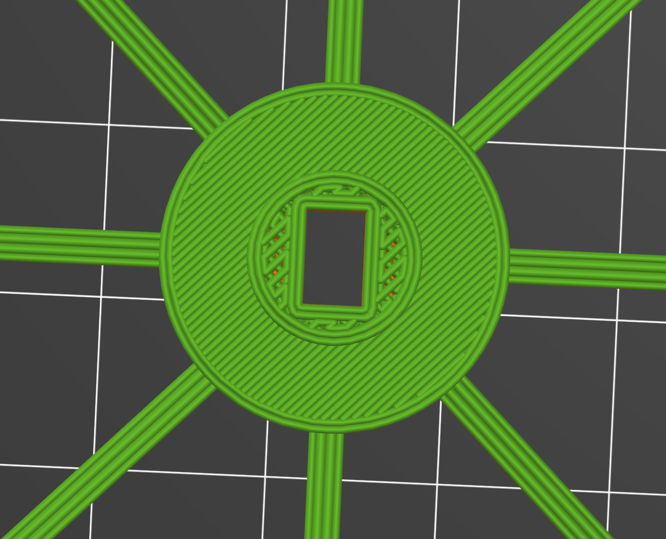
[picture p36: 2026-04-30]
images_and_videos/3D_Printing_and_Results/12.png

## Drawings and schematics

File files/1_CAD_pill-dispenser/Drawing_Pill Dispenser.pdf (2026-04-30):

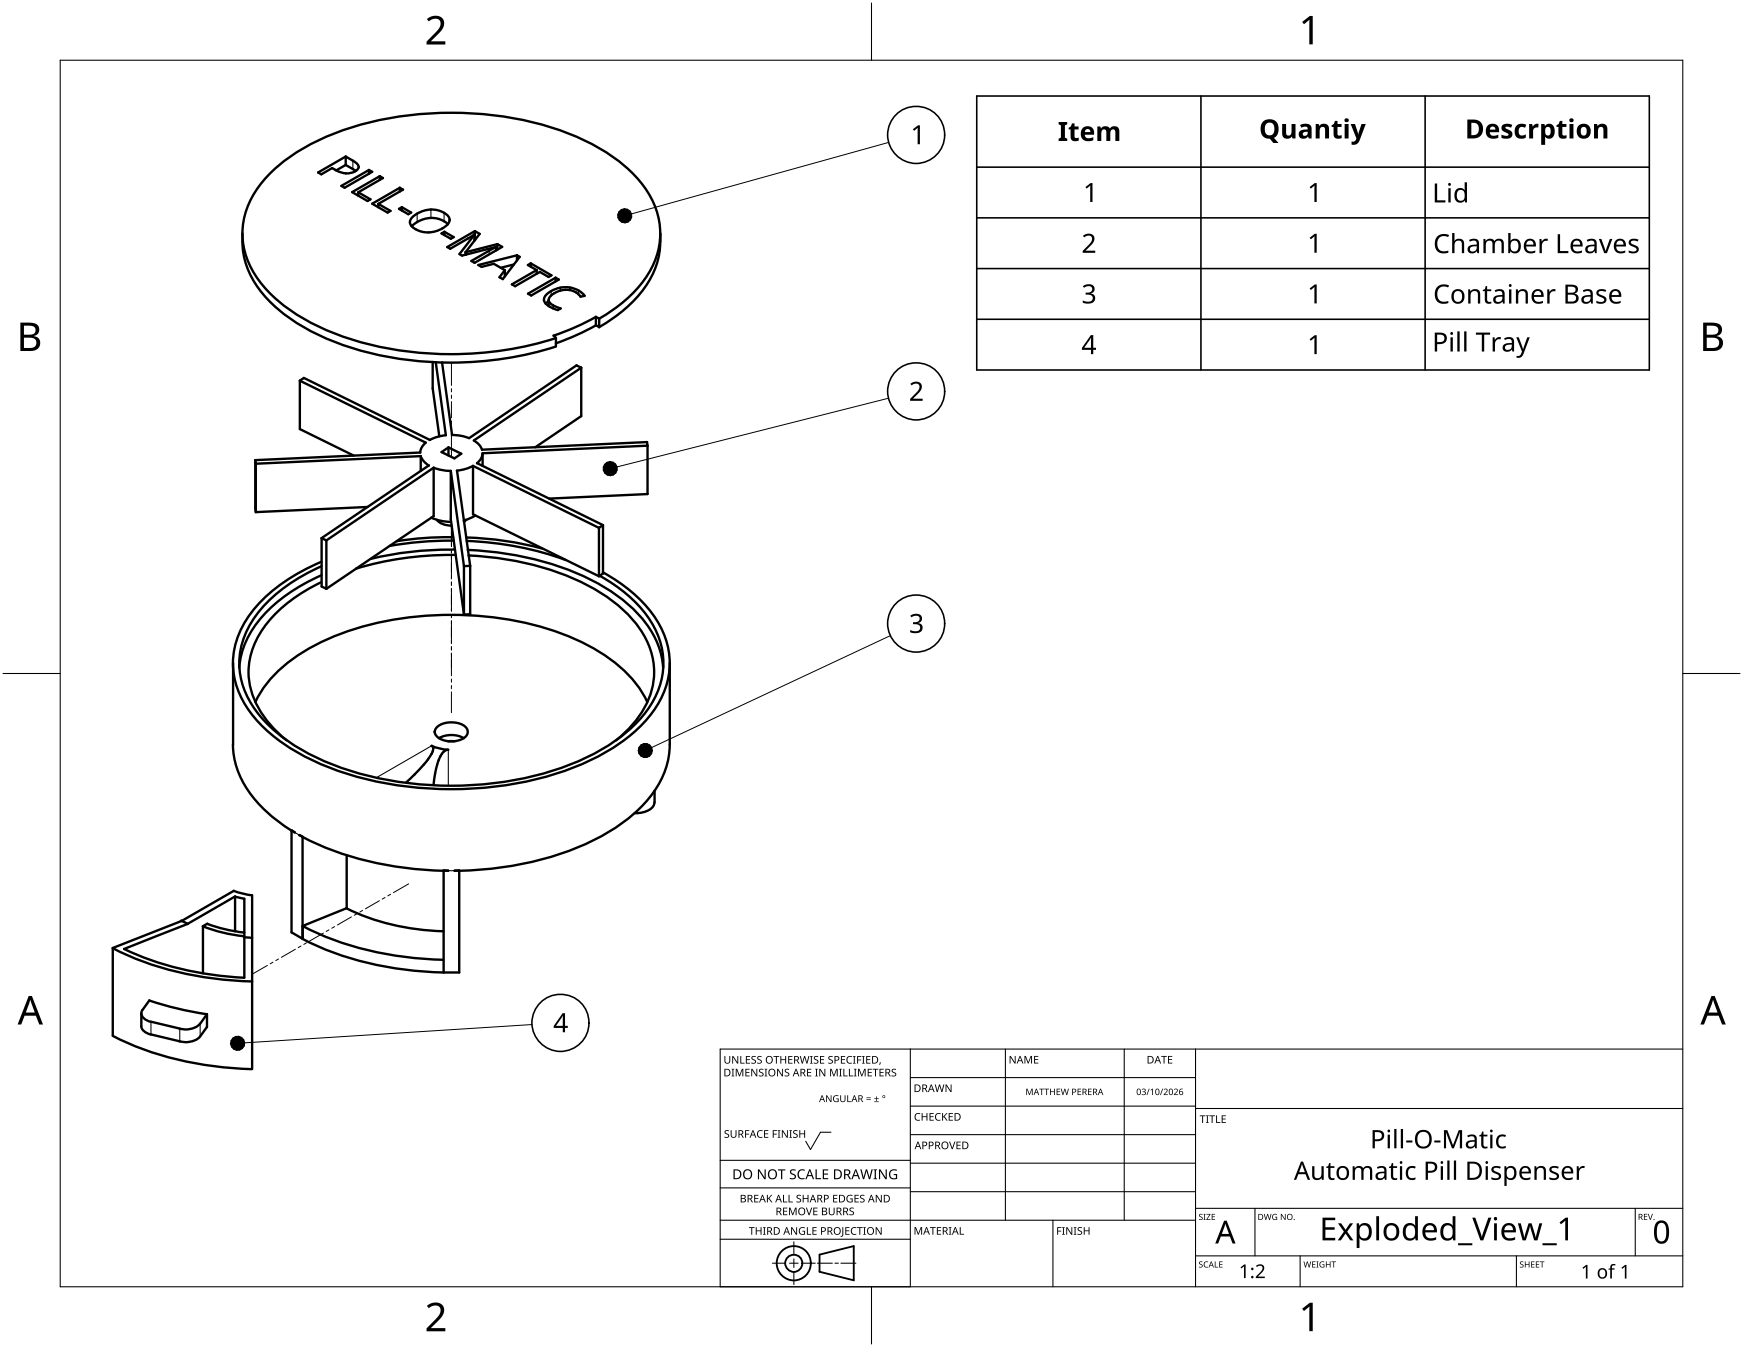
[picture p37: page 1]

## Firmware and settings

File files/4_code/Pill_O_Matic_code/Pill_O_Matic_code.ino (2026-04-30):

#include <Wire.h>          // Enables I2C communication for the RTC module
#include <RTClib.h>        // DS3231 RTC library
#include <Stepper.h>       // Stepper motor library

// ======================================================
// RTC SETUP
// ======================================================
RTC_DS3231 rtc;            // Create RTC object

// ======================================================
// PIN DEFINITIONS
// ======================================================
const int hallPin = A0;    // SS49E Hall sensor output pin

const int redLedPin = 6;   // RED LED: tray status
const int greenLedPin = 5; // GREEN LED: pill waiting in tray

// Stepper motor physical wiring to ULN2003:
// D8  -> IN1
// D9  -> IN2
// D10 -> IN3
// D11 -> IN4
//
// Stepper library pin order is intentionally set to
// 8, 10, 9, 11 for correct coil activation sequence.
const int motorPin1 = 8;   // First pin in software stepping sequence
const int motorPin2 = 10;  // Second pin in software stepping sequence
const int motorPin3 = 9;   // Third pin in software stepping sequence
const int motorPin4 = 11;  // Fourth pin in software stepping sequence

// ======================================================
// STEPPER SETUP
// ======================================================
const int stepsPerRevolution = 2048;   // 28BYJ-48 output shaft steps per full revolution
const int stepsPerDose = 256;          // 2048 / 8 = 256 steps = 45 degrees = one compartment move

Stepper stepperMotor(stepsPerRevolution, motorPin1, motorPin2, motorPin3, motorPin4);

// ======================================================
// HALL SENSOR THRESHOLDS
// Based on measured values:
// tray inserted ~533
// tray removed  ~518
// ======================================================
const int trayInThreshold  = 528;      // If reading rises to this or above, tray is considered inserted
const int trayOutThreshold = 523;      // If reading drops to this or below, tray is considered removed

// ======================================================
// DAILY DOSE SCHEDULE
// Add or remove entries as needed
// Example schedule below
// ======================================================
const int numDoseTimes = 7;            // Total number of scheduled daily dose times

int doseHours[numDoseTimes]   = {10, 10, 10, 10, 10, 10, 10};   // Scheduled hours (set hours here)
int doseMinutes[numDoseTimes] = {46, 46, 46, 46, 46, 47, 47};          // Scheduled minutes (set minutes here)
//int doseSeconds[numDoseTimes] = {10, 20, 30, 40, 50, 00, 55};   // Uncomment to include seconds accuracy (set seconds here)

bool doseTriggered[numDoseTimes] = {false};   // Automatically initializes all entries to false

// ======================================================
// SYSTEM STATE VARIABLES
// ======================================================
bool trayInPlace = false;              // Current tray state from Hall sensor
bool previousTrayInPlace = false;      // Previous tray state to detect transitions

bool pillWaiting = false;              // True after pill is dispensed and waiting in tray
int pendingDoseCount = 0;              // Counts doses that have triggered but not yet dispensed

int lastDay = -1;                      // Used to reset daily schedule flags when a new day starts

// ======================================================
// FUNCTION: turnOffStepper
// Purpose:
//   Fully de-energize all stepper coils when motor is not rotating
//   This keeps idle current near zero and prevents heating
// ======================================================
void turnOffStepper() {
  digitalWrite(motorPin1, LOW);        // Turn OFF coil 1
  digitalWrite(motorPin2, LOW);        // Turn OFF coil 2
  digitalWrite(motorPin3, LOW);        // Turn OFF coil 3
  digitalWrite(motorPin4, LOW);        // Turn OFF coil 4
}

// ======================================================
// FUNCTION: updateTrayState
// Purpose:
//   Read analog Hall sensor and update trayInPlace using hysteresis
// ======================================================
void updateTrayState() {
  int hallValue = analogRead(hallPin);   // Read Hall sensor value

  // If tray is currently considered OUT, only switch to IN when value is clearly high enough
  if (!trayInPlace && hallValue >= trayInThreshold) {
    trayInPlace = true;
  }

  // If tray is currently considered IN, only switch to OUT when value is clearly low enough
  if (trayInPlace && hallValue <= trayOutThreshold) {
    trayInPlace = false;
  }

  // Serial debug output
  Serial.print("Hall Value: ");
  Serial.print(hallValue);
  Serial.print(" | Tray: ");
  if (trayInPlace) {
    Serial.println("IN PLACE");
  } else {
    Serial.println("REMOVED");
  }
}

// ======================================================
// FUNCTION: updateRedLed
// Purpose:
//   RED LED ON when tray missing
//   RED LED OFF when tray inserted
// ======================================================
void updateRedLed() {
  if (trayInPlace) {
    digitalWrite(redLedPin, LOW);      // Tray inserted -> RED OFF
  } else {
    digitalWrite(redLedPin, HIGH);     // Tray removed/missing -> RED ON
  }
}

// ======================================================
// FUNCTION: updateGreenLed
// Purpose:
//   GREEN LED ON when a dispensed pill is waiting in tray
//   GREEN LED OFF otherwise
// ======================================================
void updateGreenLed() {
  if (pillWaiting) {
    digitalWrite(greenLedPin, HIGH);   // Pill waiting -> GREEN ON
  } else {
    digitalWrite(greenLedPin, LOW);    // No pill waiting -> GREEN OFF
  }
}

// ======================================================
// FUNCTION: dispenseOnePill
// Purpose:
//   Rotate one compartment, then de-energize motor
// ======================================================
void dispenseOnePill() {
  Serial.println("Dispensing one pill...");

  stepperMotor.step(stepsPerDose);     // Rotate 45 degrees = one compartment
  turnOffStepper();                    // Immediately remove holding current after motion

  pillWaiting = true;                  // Pill is now waiting in tray
  updateGreenLed();                    // Turn GREEN LED ON

  Serial.println("Dispense complete -> GREEN LED ON");
}

// ======================================================
// FUNCTION: checkScheduledDoseTimes
// Purpose:
//   Compare current RTC time against all preset time slots
//   Each matching slot adds one pending dose only once per day
// ======================================================
void checkScheduledDoseTimes(DateTime now) {
  for (int i = 0; i < numDoseTimes; i++) {

    // Only trigger this slot if it has not already triggered today
    if (!doseTriggered[i] &&
        now.hour() == doseHours[i] &&
        now.minute() == doseMinutes[i]
         // && now.second() == doseSeconds[i]   // Uncomment to include seconds accuracy
       ) {

      doseTriggered[i] = true;         // Mark this time slot as triggered for today
      pendingDoseCount++;              // Add one pending dose

      Serial.print("Scheduled dose triggered at ");
      if (doseHours[i] < 10) Serial.print("0");
      Serial.print(doseHours[i]);
      Serial.print(":");
      if (doseMinutes[i] < 10) Serial.print("0");
      Serial.print(doseMinutes[i]);

       //Serial.print(":");                              // Uncomment to include seconds accuracy
       //if (doseSeconds[i] < 10) Serial.print("0");    // Uncomment to include seconds accuracy
       //Serial.print(doseSeconds[i]);                  // Uncomment to include seconds accuracy

      Serial.print(" | Pending doses = ");
      Serial.println(pendingDoseCount);
    }
  }
}

// ======================================================
// FUNCTION: resetDailyScheduleIfNeeded
// Purpose:
//   At the start of a new day, allow all scheduled slots to trigger again
// ======================================================
void resetDailyScheduleIfNeeded(DateTime now) {
  if (now.day() != lastDay) {
    lastDay = now.day();               // Store new day

    for (int i = 0; i < numDoseTimes; i++) {
      doseTriggered[i] = false;        // Reset all daily trigger flags
    }

    Serial.println("New day detected -> daily schedule reset");
  }
}

// ======================================================
// FUNCTION: printCurrentTime
// Purpose:
//   Print RTC time to Serial Monitor
// ======================================================
void printCurrentTime(DateTime now) {
  Serial.print("Time: ");
  Serial.print(now.year());
  Serial.print("/");
  if (now.month() < 10) Serial.print("0");
  Serial.print(now.month());
  Serial.print("/");
  if (now.day() < 10) Serial.print("0");
  Serial.print(now.day());
  Serial.print("  ");

  if (now.hour() < 10) Serial.print("0");
  Serial.print(now.hour());
  Serial.print(":");
  if (now.minute() < 10) Serial.print("0");
  Serial.print(now.minute());
  Serial.print(":");
  if (now.second() < 10) Serial.print("0");
  Serial.println(now.second());
}

// ======================================================
// SETUP
// ======================================================
void setup() {
  Serial.begin(9600);                  // Start Serial Monitor
  Wire.begin();                        // Start I2C bus

  // Set LED pins as outputs
  pinMode(redLedPin, OUTPUT);
  pinMode(greenLedPin, OUTPUT);

  // Set stepper pins as outputs
  pinMode(motorPin1, OUTPUT);
  pinMode(motorPin2, OUTPUT);
  pinMode(motorPin3, OUTPUT);
  pinMode(motorPin4, OUTPUT);

  // Initialize LEDs OFF
  digitalWrite(redLedPin, LOW);
  digitalWrite(greenLedPin, LOW);

  // Set stepper speed
  stepperMotor.setSpeed(10);           // 10 RPM is a safe working speed for this motor

  // Make sure motor starts fully de-energized
  turnOffStepper();

  // Start RTC
  if (!rtc.begin()) {
    Serial.println("RTC not found");
    while (1) {                        // Stop here if RTC is not detected
    }
  }

  // Uncomment this ONCE to set RTC to compile/upload time, then comment it again
  // rtc.adjust(DateTime(F(__DATE__), F(__TIME__)));

  Serial.println("System started");
}

// ======================================================
// LOOP
// ======================================================
void loop() {
  DateTime now = rtc.now();            // Read current RTC time

  printCurrentTime(now);               // Print current time to Serial Monitor

  // Step 1: reset dose flags if a new day has started
  resetDailyScheduleIfNeeded(now);

  // Step 2: update Hall sensor / tray state
  updateTrayState();

  // Step 3: update RED LED from tray state
  updateRedLed();

  // Step 4: detect tray removal AFTER a pill was dispensed
  // This implements:
  // tray removed while pillWaiting == true -> user is taking pill
  if (previousTrayInPlace == true && trayInPlace == false && pillWaiting == true) {
    pillWaiting = false;               // Pill has been taken
    updateGreenLed();                  // Turn GREEN LED OFF
    Serial.println("Tray removed while pill waiting -> GREEN LED OFF, pillWaiting = false");
  }

  // Step 5: remember tray state for next loop
  previousTrayInPlace = trayInPlace;

  // Step 6: check all scheduled times and add pending doses
  checkScheduledDoseTimes(now);

  // Step 7: dispense only if:
  // - there is at least one pending dose
  // - tray is inserted
  // - no previous pill is still waiting
  if (pendingDoseCount > 0 && trayInPlace == true && pillWaiting == false) {
    dispenseOnePill();                 // Dispense one dose
    pendingDoseCount--;                // One pending dose has now been dispensed

    Serial.print("Pending doses remaining = ");
    Serial.println(pendingDoseCount);
  }

  // Step 8: if tray is missing and a dose is pending, do not dispense yet
  if (pendingDoseCount > 0 && trayInPlace == false) {
    Serial.println("Dose pending, but tray missing -> waiting for tray insertion");
  }

  // Step 9: if nothing is moving, keep motor fully OFF
  turnOffStepper();

  delay(200);                          // Small loop delay for stable operation
}
